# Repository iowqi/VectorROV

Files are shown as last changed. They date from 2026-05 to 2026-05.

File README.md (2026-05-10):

# VectorROV



**Languages:** [English](README.md) · [中文](README.zh-CN.md)

Open-source **tethered underwater ROV** platform built around **four vectored thrusters**, **dual fisheye panoramic perception**, and a VR-oriented teleoperation stack. This repository accompanies a **graduate design project** ([Fujian University of Technology](https://www.fjut.edu.cn/) · Computer Science) that stitches together mechanics, embedded control, edge vision/streaming, and simulation-based control experiments.

The vehicle targets highly maneuverable motion with an **8-actuator** layout (four steering motors + four thrusters) and leaves room for **dual expandable 6‑DOF manipulators** (see [TODO](#todo)).

---

## 🤖 Prototype at a glance

<p align="center">
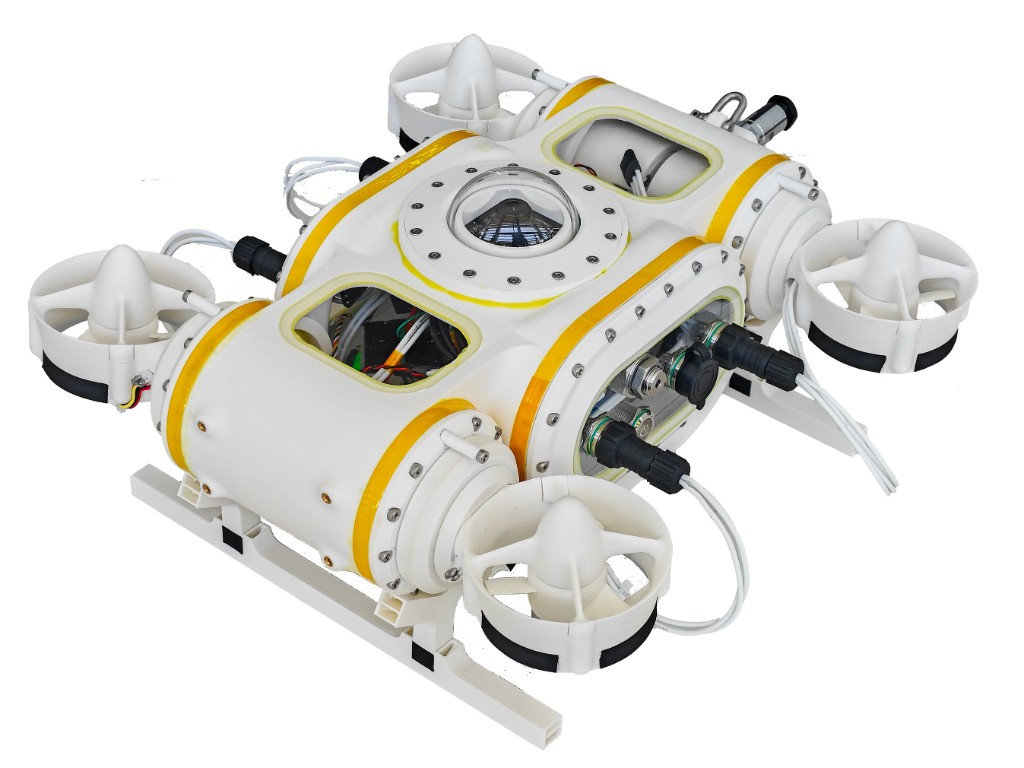
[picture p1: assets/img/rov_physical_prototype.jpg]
VectorROV physical prototype
  
</p>

<p align="center"><em>Physical prototype: four shrouded thrusters, sealed hull & domes, sled-type display stand, and bulkhead interfaces for tether/power.</em></p>

---

## ✨ Highlights

- **🧭 Four-vector propulsion** — vectored thrusters for richer force/moment authority; magnetic quick-release watertight passages for maintenance (see thesis mechanical chapter).
- **⚙️ STM32H723 + CAN** — dual **FDCAN** buses: steering (DM3510 class) vs. propulsion (**VESC / FOC**); IMU + pressure feedback for closed-loop state estimation.
- **👁️ Panorama → NDI → VR** — dual fisheye **stitch** on a **Radxa Dragon Q6A**-class edge node, **NDI** streaming, buoy Wi‑Fi hop to headset; lightweight **YOLO**-style detection with a “edge primary / client fallback” path.
- **🎮 MuJoCo + SB3** — simulation environment for control validation and **reinforcement-learning** experiments (Stable-Baselines3), aligned with the same action/state semantics as the real stack where possible.
- **🧰 CAD & tooling** — `hardware/` mechanical sources; `tools/OpenProp/` for propeller/motor analysis workflows.

### Measured/Pilot metrics (lab)

From integrated testing described in the thesis: panoramic pipeline about **~20 fps**, **capture → stitch → NDI** latency about **&lt;100 ms** (before headset render); single thruster thrust roughly **8–10 N** (estimated range).

---

## 🏗️ Architecture diagrams

| System overview (Ch.2) | Electronics & comms (Ch.2) |
|:-:|:-:|
| System overview | Electronics subsystem |

| Vision & streaming (Ch.2) | Attitude control & allocation (Ch.4) |
|:-:|:-:|
| Vision pipeline | Attitude control |

---

## 🗂️ Repository layout

| Path | Role |
|---|---|
| `assets/diagrams/` | Thesis figures (SVG): architecture, subsystems, simulation |
| `assets/img/` | Photos & renders (e.g., prototype) |
| `firmware/` | `CtrBoard-H7_CAN/` (H7 main), `F103C8T6/`, `N630/` — USB/CAN/motor control |
| `hardware/` | CAD & part sources (shells, thrusters, connectors, arms, etc.) |
| `control/MuJoCoSim/` | MuJoCo scenes, training scripts, logs/models for SB3 experiments |
| `pytest/` | Python-side checks (may ship a local `.venv`) |
| `tools/OpenProp/` | OpenProp examples & sources for prop analysis |

---

## 🚀 Getting started (pointers)

**Firmware:** Open `firmware/CtrBoard-H7_CAN/MDK-ARM` in **Keil MDK** (STM32H7). Expect long build trees—work from CubeMX-exported project files already in-repo.

**Simulation / RL:** See `control/MuJoCoSim/` — create a clean virtual environment, install MuJoCo / Gymnasium / Stable-Baselines3 stack as used by the training scripts there, then run training or evaluation entrypoints (see files under `train/`).

**Vision / NDI / edge:** Runtime primarily targets the **Q6A** edge device for stitching & inference; VR display assumes a receiver path (e.g., NDI + headset app). Treat this repo as the **system reference + firmware/hardware/sim** anchor; edge images may live on device or separate release artifacts.

---

## 🎓 Academic context

This platform is developed as a **final-year capstone / graduation design** project:

**“Design and Implementation of an Underwater ROV VR Platform with Integrated Visual Perception.”**  
It emphasizes **end-to-end integration**—mechanics, embedded control, panoramic vision, and simulation—rather than a single algorithmic benchmark. A full narrative, equations, and experiment logs appear in the student thesis manuscript (not shipped in this repo as required reading).

---

## TODO

Work that is **partially done**, **not production-ready**, or **not yet started**:

- [ ] **Reinforcement learning** — expand SB3/MuJoCo training, reward design, sim-to-real safeguards, and logging/replay for the physical ROV.
- [ ] **Dual 6‑DOF manipulators** — mechanical integration, water‑tight routing, arm control stack, and teleoperation UX (hardware CAD folders exist; full arm workflow is incomplete).
- [ ] **Meta Quest 2 VR client** — production-quality **Quest 2** client (latency-hardened rendering, interaction, connectivity with NDI/stream stack); **little or no** usable client is in-tree yet.

Contributions and issue reports are welcome.

---

## 📄 License

This project is released under the **MIT License** — see [`LICENSE`](LICENSE).

---

## 🙏 Acknowledgements

Thanks to thesis advisors and lab partners who supported machining, wet testing prep, and embedded bring-up. Third-party MCU stacks (STM32 HAL, FreeRTOS, USB stacks) remain under their respective licenses inside `firmware/`.

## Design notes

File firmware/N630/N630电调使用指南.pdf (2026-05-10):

# N630电调使用指南

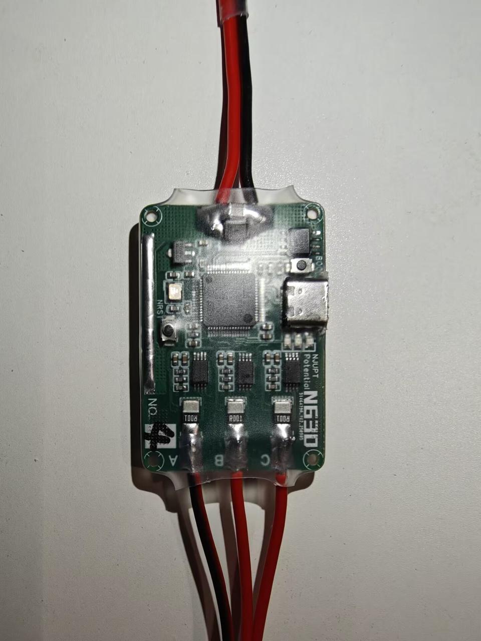
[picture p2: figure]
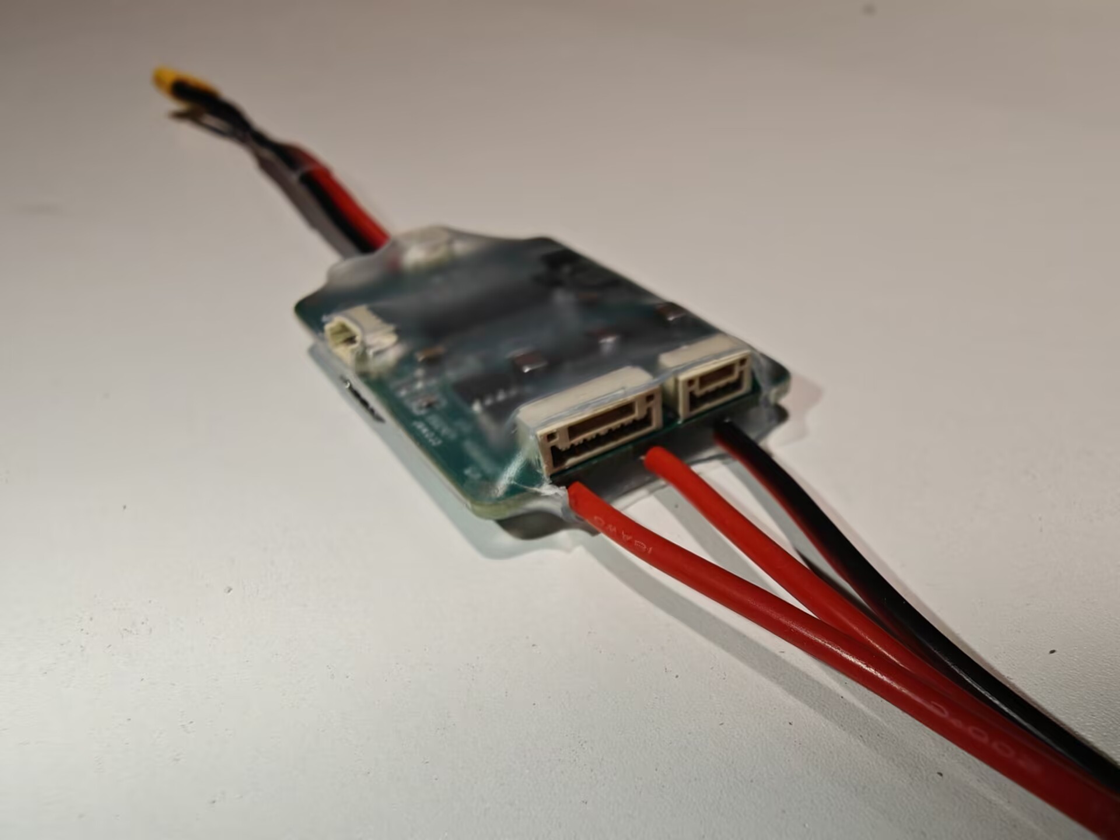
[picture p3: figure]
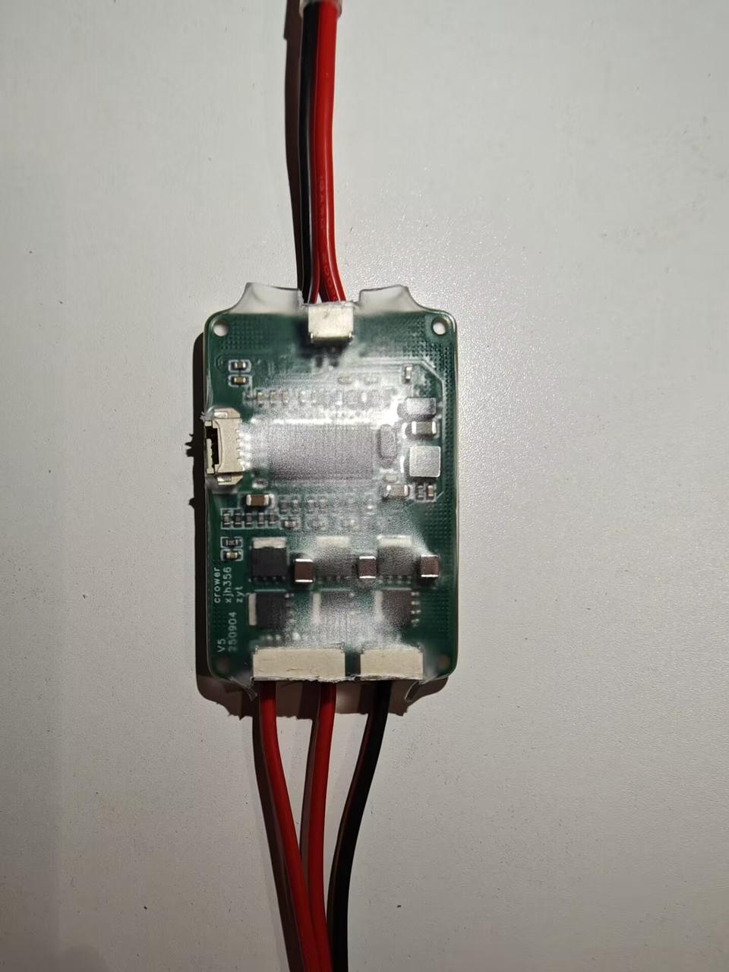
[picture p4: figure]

N630电调基于VESC项目进行设计，硬件在vesc6原版设计上进行精简，支持VESC官方上位机调参，支 持有感/无感驱动直流无刷电机，支持M3508、M2006电机编码器接入。

编译固件只需要修改采样电阻和电流放大器参数（N630电调的采样电阻为1mR，电流放大器倍数为 50）。

## 1. 线路连接

1. 将N630电调的三相线连接M3508电机，7Pin口可根据需要选择是否连接。若连接7Pin口，可使用 编码器闭环模式，可读到电机温度（过温保护功能有效）；若不连接7Pin口，仍可使用高频注入实 现零速力矩保持，但不可闭位置环。
2. 将N630电调连接电池供电。强烈建议使用电池供电，调压电源无法吸收电流，电机刹车会导致母 线电压升高，烧毁电调和母线上的其他设备！
3. 使用Type-C数据线将N630电调连接电脑。

## 2. 电机校准

1. 启动 vesc_tool_6.05.exe
2. 点击软件右上角连接按钮

2. 恢复默认设置，依次点击右侧按钮

第一个按钮是恢复默认参数，第二个按钮是写入到电机

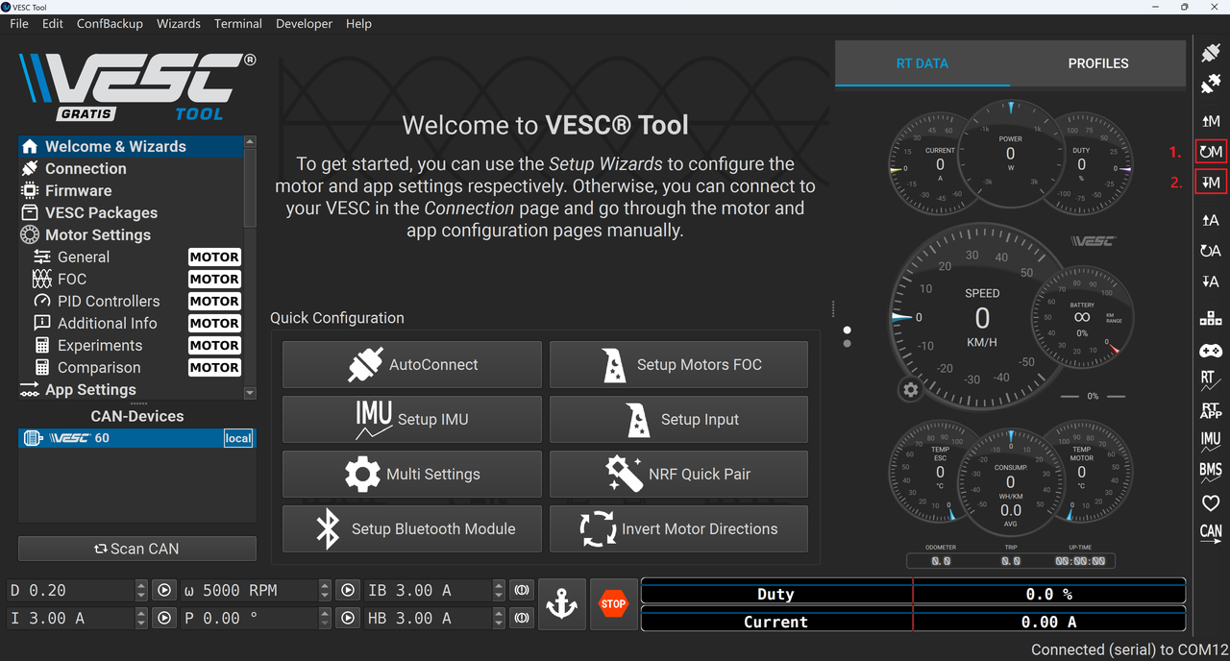
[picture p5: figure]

3. 点击左侧 General 选项卡，设置最大电流

对于M3508，设置最大电流为20A，最大刹车电流为-20A（如果使用电源调试，请设置为0A，以免烧 毁电调和母线上的其他设备）

绝对最大电流设置为60A（最大电流的三倍，超过此电流将触发报错）

4. 电机左侧 FOC 选项卡，校准电机

点击 RL 按钮后，电机会发出尖锐的声音，是在测量相电阻、相电感

点击 λ 按钮后，电机会开始转动，是在测量磁链

点击 Apply 按钮，会自动计算电流环 PI 参数

点击 ⬇M 按钮，写入参数到电机

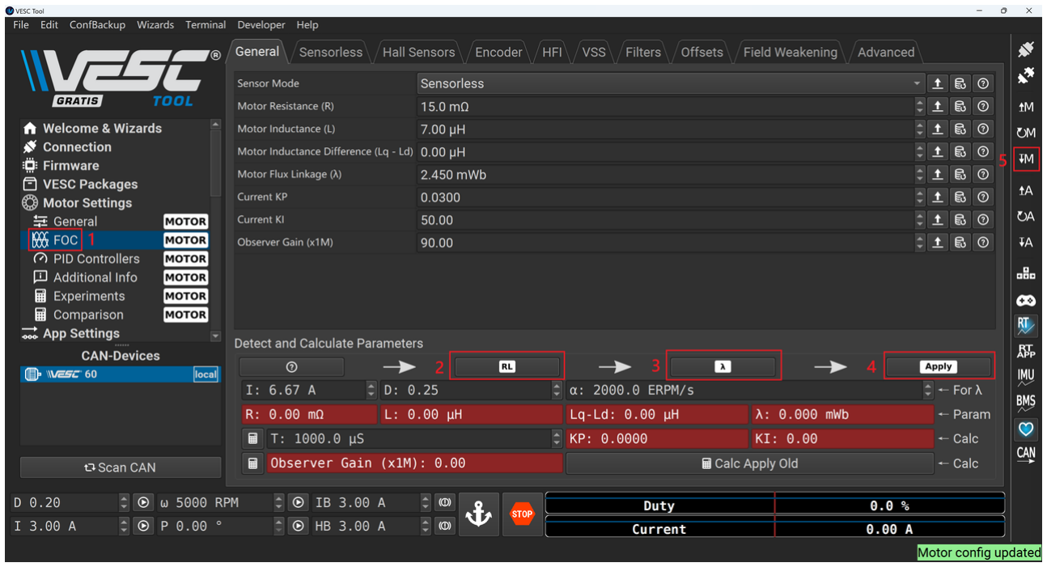
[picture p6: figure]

## 3. 首次运行

此时电机可在无感模式下运行（基于磁链观测器进行FOC控制）

点开右侧栏 RT 按钮，可实时查看电机占空比和电流，出现任何问题可点击右侧 STOP 停止，注意不能 让电机长时间通过大电流

可分别尝试占空比模式、电流模式，初次尝试请用较小的值

- 设置占空比为5%，电机开始低速转动，点击右侧 STOP 按钮停止
- 设置电流为0.5A，电机开始加速运动（直至最大速度），可随时点击右侧 STOP 按钮停止

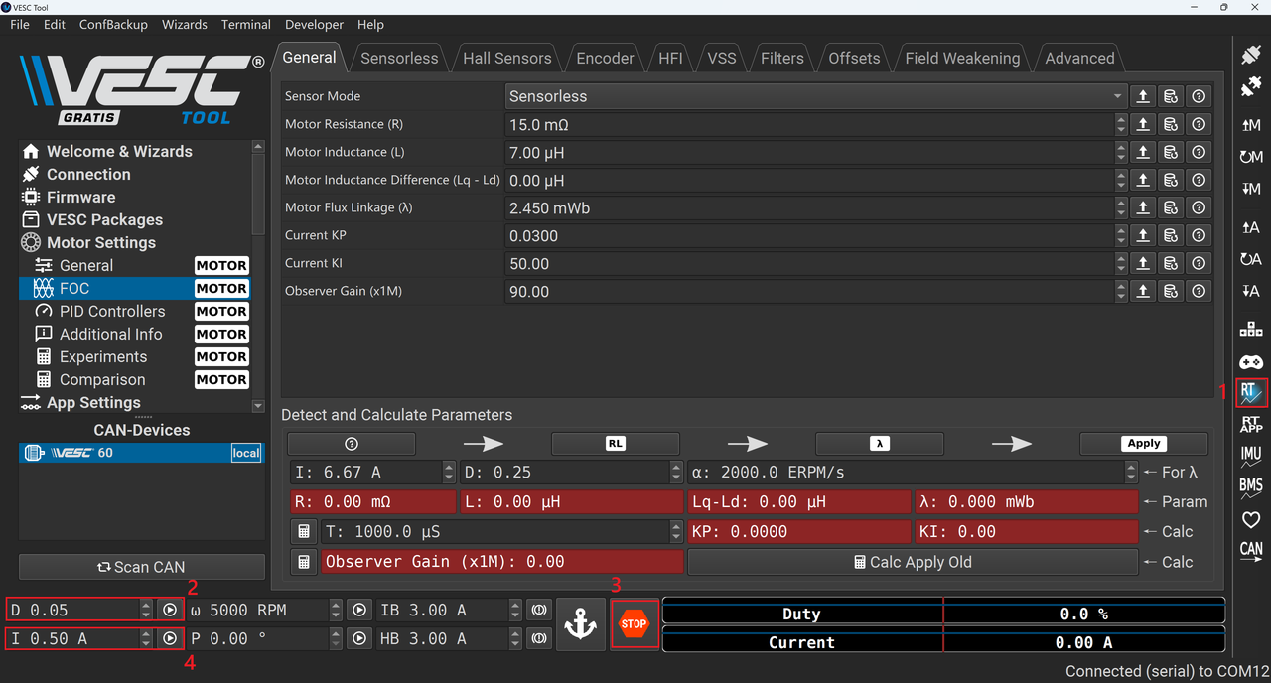
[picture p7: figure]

## 4. 使用高频注入，实现零速力矩保持

切换模式为HFI（高频注入），点击右侧 ⬇M 保存

设置 占空比5% 运行，此时电机会转动同时发出高频声音，这是正常现象

尝试用手捏住电机，能感受到电机在堵转时仍然能保持力矩输出

## 5. 使用编码器模式

M3508 7Pin 定义如下，编码器类型为 sin/cos 编码器

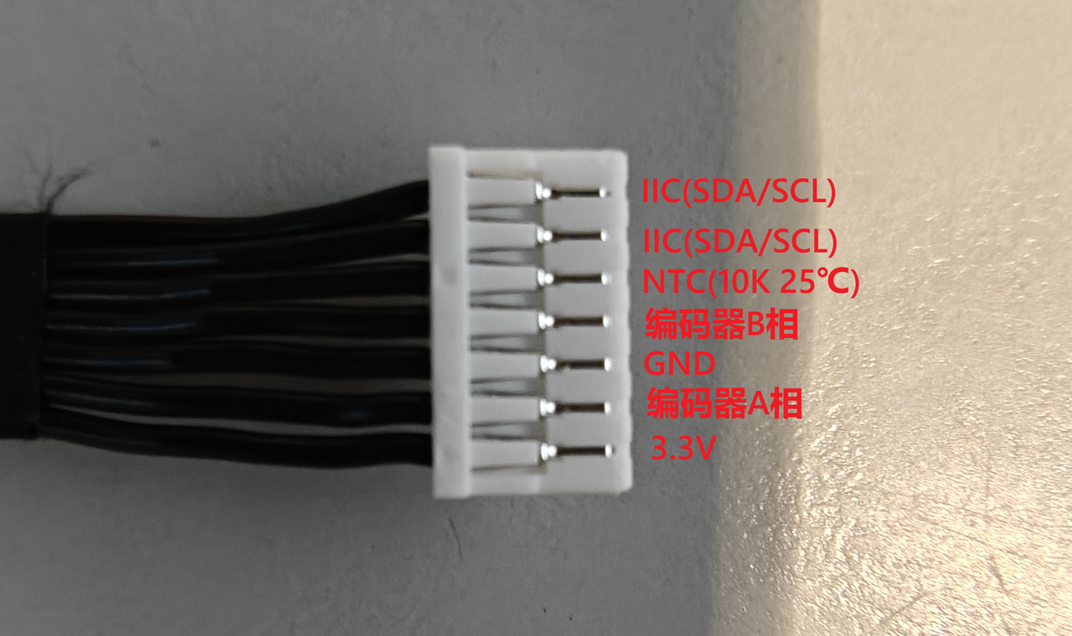
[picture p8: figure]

点击左侧 General 选项卡，修改编码器类型为 Sin/Cos Encoder，修改编码器幅值为 0.75V，偏置为 1.0V

注：此处幅值为单边幅值，编码器输出信号峰峰值为1.5V

设置完成后，点击右侧栏 ⬇M 保存配置

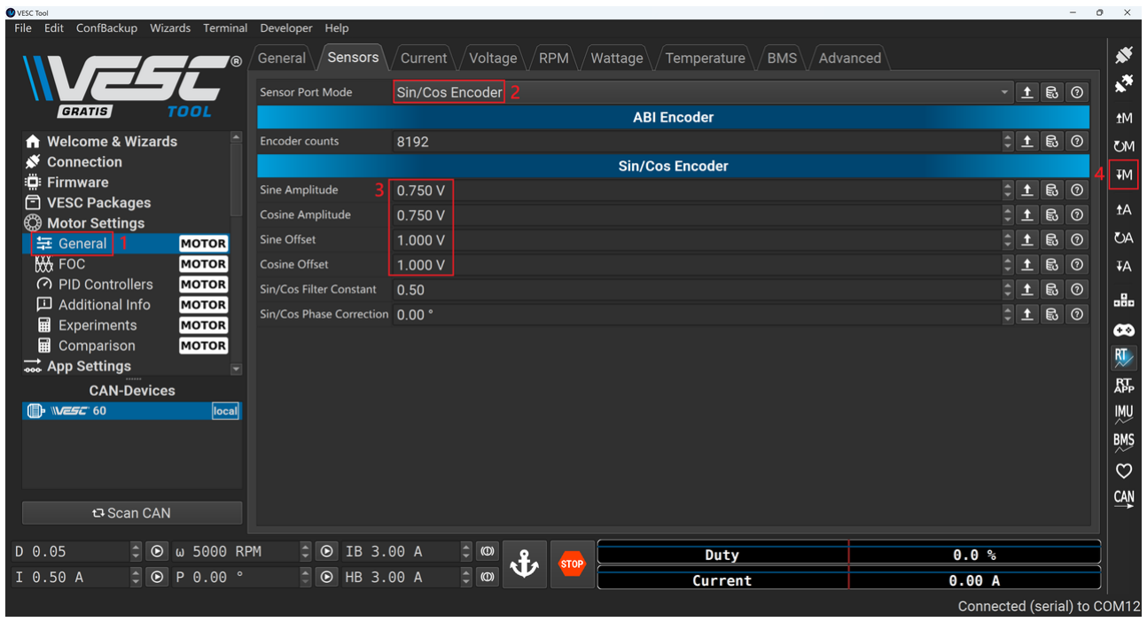
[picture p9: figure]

校准编码器

- 点击左侧 FOC 选项卡，切换到 Encoder 子选项
- 输入 5A 电流运行校准（建议使用电机最大电流的1/4，过大的电流容易烧毁电机）
- 电机开始缓慢转动，等待校准成功提示（若校准卡住超过1分钟，请检查编码器连线）
- 应用并写入配置

编码器模式设置完成后，可尝试给5%占空比，用手捏住电机，测试堵转力矩保持

## 6. 速度环与位置环

无感模式可以闭速度环，编码器模式可以闭速度环和位置环，可在左侧 PID Controllers 选项卡调节 PID参数（默认参数效果不好）

注：速度单位为电角度（ERPM），M3508的极对数为7，所以转子转一圈为7个电角度，如果有减速箱 需要另外计算。闭位置环时，请算好输出轴转一圈是多少电角度，填入 PID Controllers -> Position Angle Division

## 7. CAN通信

默认CAN通信波特率为500K，可在下图位置修改

此处为修改 App Settings，保存请使用 ⬇A 按钮

CAN通信格式详见：
https://github.com/vedderb/bldc/blob/master/documentation/comm_can.md

## 8. 更新固件

截止目前，vesc已推出 6.06 版本。若要适配新版本，需要自行修改固件参数进行编译。步骤如下

1. 克隆vesc官方代码：https://github.com/vedderb
2. 修改参数，hwconf/trampa/vesc6/hw_60_core.h 文件
a. 修改 CURRENT_AMP_GAIN 为 50.0
b. 修改 CURRENT_SHUNT_RES 为 0.001
3. 按照 README 文件配置好环境后，使用 make 60 命令编译
4. 可使用官方上位机或stm32烧录工具写入固件

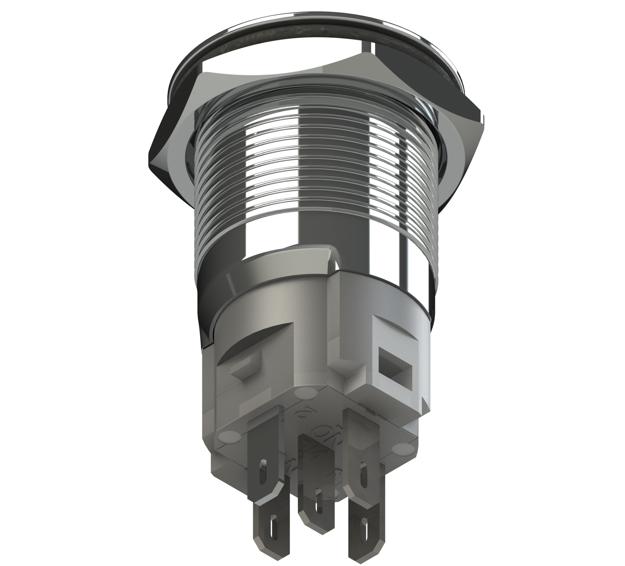
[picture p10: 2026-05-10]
hardware/LED_Button16mm/Button_16mm_2.png

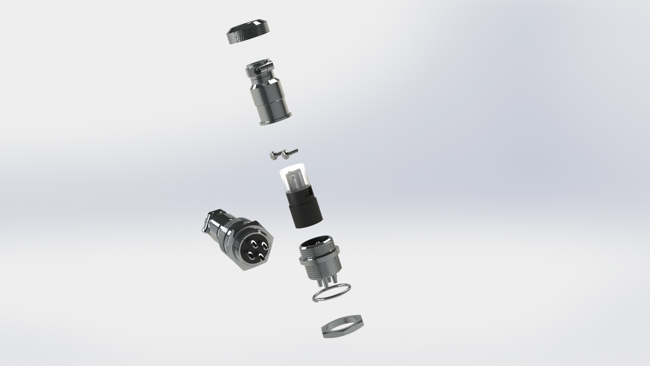
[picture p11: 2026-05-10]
hardware/gx16-connector/Connetor GX16.JPG

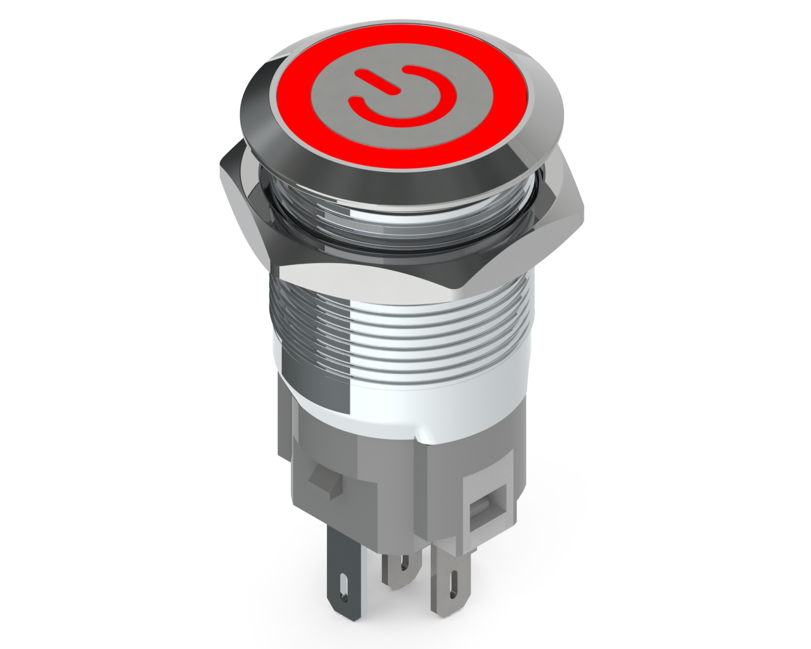
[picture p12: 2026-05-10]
hardware/LED_Button16mm/Button_16mm_1.png

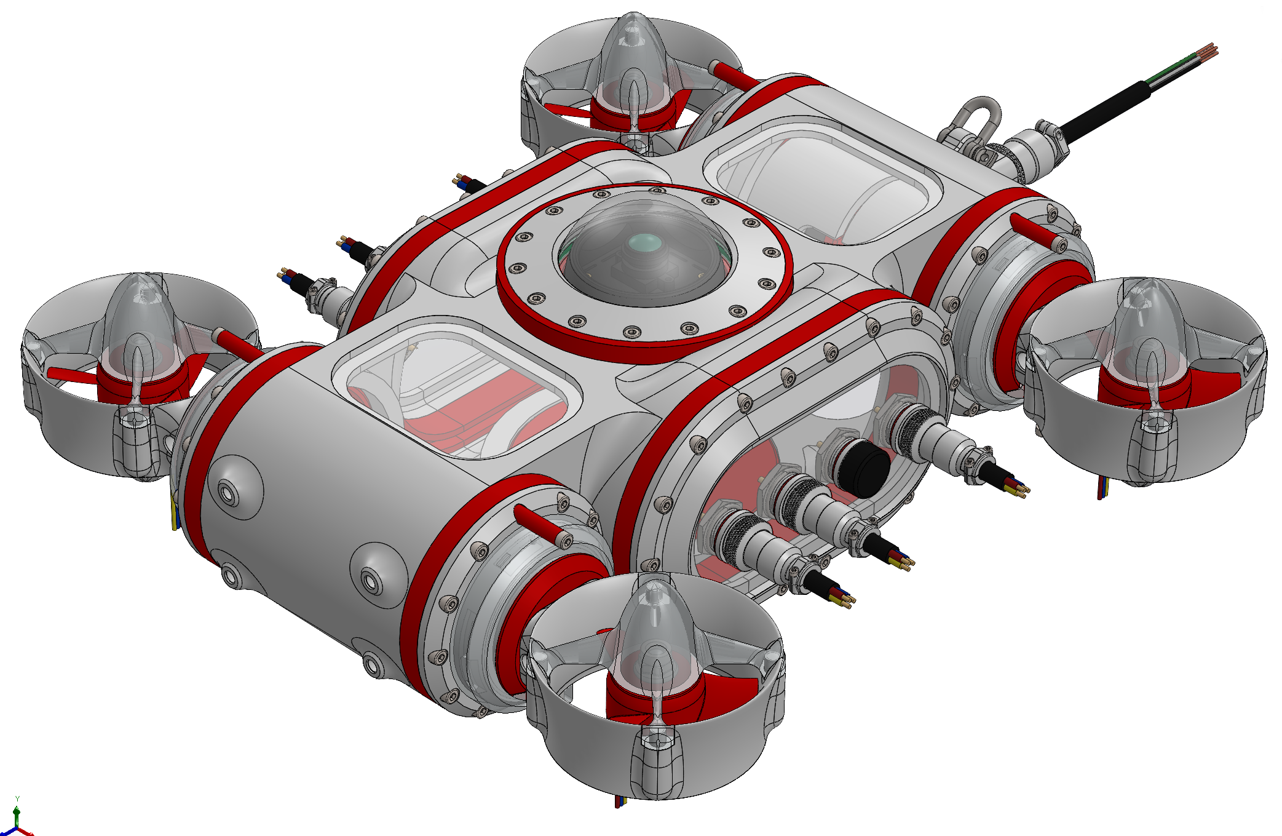
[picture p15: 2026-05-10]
assets/img/rov_prototype.png

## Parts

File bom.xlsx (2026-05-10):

分类 | 名称/链接 | 规格 | 价格 | 批量 | 单价 | 运费 | 数量 | 总价 | 类总价 | BOM总价
密封圈 | 氟胶O型圈 (https://item.taobao.com/item.htm?id=673574488705&from=cart&skuId=5711071359906&upStreamPrice=1620) | 外径112*4 | 16.2 | 2 | 8.1 | 0 | 2 | 16.2 | 26.3 | 2688.9828
 | 氟胶O型圈 (https://item.taobao.com/item.htm?id=774230751154&from=cart&skuId=5469033463785&upStreamPrice=330) | 外径60*4 | 3.3 | 2 | 1.65 | 0 | 4 | 6.6
 | 氟胶O型圈 (https://item.taobao.com/item.htm?id=774230751154&from=cart&skuId=5469033463787&upStreamPrice=350) | 外径70*4 | 3.5 | 2 | 1.75 | 0 | 2 | 3.5
电池 | 6S远航电池 (https://item.taobao.com/item.htm?id=838880984185&from=cart&skuId=5946761481635&upStreamPrice=15930) | 亿纬6S1P | 159.3 | 1 | 159.3 | 0 | 1 | 159.3 | 191.3
 | 三元锂电保护板 (https://item.taobao.com/item.htm?id=875391725096&from=cart&skuId=5880358639395&upStreamPrice=3200) | 6S 50A+NTC温感 | 32 | 1 | 32 | 0 | 1 | 32
电子 | GC2093摄像头 | - | 60 | 1 | 60 | 0 | 2 | 120 | 1239
 | IP68防水开关 (https://item.taobao.com/item.htm?id=797044978629&from=cart&skuId=5435698057369&upStreamPrice=2000) | 白色灯自复16mm | 20 | 1 | 20 | 0 | 1 | 20
 | 瑞莎Q6A (https://item.taobao.com/item.htm?id=962936728970&from=cart&skuId=6119740358776&upStreamPrice=87900) | 12G+256固态 | 1099 | 1 | 1099 | 0 | 1 | 1099
 | N630电调 (https://oshwhub.com/njupt-robomasters/n630) | - | 30 | 1 | 30 | 0 | 4 | 120
 | 2312A无刷电机 (https://item.taobao.com/item.htm?id=965539482681) | 正螺纹 | 8.8 | 1 | 8.8 | 6 | 4 | 41.2
 | DMH3510 (https://item.taobao.com/item.htm?id=871173947758&from=cart&skuId=5872003791067&upStreamPrice=22000) | 电机(含驱动) | 220 | 1 | 220 | 12 | 4 | 892
磁铁 | 圆柱形磁铁 (https://item.taobao.com/item.htm?id=918274679105&from=cart&skuId=5956275279443&upStreamPrice=1125) | 5x15mm | 11.25 | 20 | 0.5625 | 0 | 16 | 9 | 66.472
 | 圆柱形磁铁 (https://item.taobao.com/item.htm?id=918274679105&from=cart&skuId=5956275279439&upStreamPrice=550) | 5x5mm | 5.5 | 20 | 0.275 | 0 | 32 | 8.8
 | 圆柱形磁铁 (https://item.taobao.com/item.htm?id=918274679105&from=cart&skuId=5956275279463&upStreamPrice=1521) | 10x15mm | 15.21 | 10 | 1.521 | 0 | 32 | 48.672
轴承 | 尼龙POM轴承 (https://item.taobao.com/item.htm?id=782440333215&from=cart&skuId=5341835656817&upStreamPrice=370) | 6006-2RS(密封) | 3.7 | 1 | 3.7 | 0 | 4 | 14.8
 | 深沟球轴承 (https://item.taobao.com/item.htm?id=619718750156&from=cart&skuId=5738161741449&upStreamPrice=270) | 61806-2RS | 2.7 | 1 | 2.7 | 0 | 4 | 10.8
连接器 | GX16航空插头 (https://item.taobao.com/item.htm?id=715467235763&from=cart&skuId=5175080435883&upStreamPrice=20) | GX16-10芯{整套) | 5.2 | 1 | 5.2 | 0 | 7 | 36.4
紧固件 | 304法兰防松螺母 (https://item.taobao.com/item.htm?id=601483825433&from=cart&skuId=5351621079821&upStreamPrice=142) | M6 | 2.75 | 5 | 0.55 | 0 | 4 | 2.2 | 28.7108
 | 热熔螺母 (https://item.taobao.com/item.htm?id=829126153985&from=cart&skuId=5576291013934&upStreamPrice=920) | M3*6*5 | 12.8 | 80 | 0.16 | 0 | 116 | 18.56
 | 杯头内六角 (https://item.taobao.com/item.htm?id=39229349352) | M3X30 | 2.77 | 20 | 0.1385 | 0 | 4 | 0.554
 | 杯头内六角 (https://item.taobao.com/item.htm?id=829276904010&from=cart&skuId=5739116711092&upStreamPrice=706) | M3X10 | 3.79 | 100 | 0.0379 | 0 | 84 | 3.1836
 | 杯头内六角 (https://item.taobao.com/item.htm?id=829276904010&from=cart&skuId=5739116711092&upStreamPrice=706) | M3X8 | 3.79 | 100 | 0.0379 | 0 | 60 | 2.274
 | 杯头内六角 (https://item.taobao.com/item.htm?id=39229349352) | M3X5 | 2.62 | 50 | 0.0524 | 0 | 4 | 0.2096
 | 杯头内六角 (https://item.taobao.com/item.htm?id=732630255887) | M2.5X10 | 3.2 | 100 | 0.032 | 0 | 24 | 0.768
 |  | M2.5X15 | 2.13 | 100 | 0.0213 | 0 | 16 | 0.3408
 | 沉头内梅花 (https://item.taobao.com/item.htm?id=42092422468) | M3X5 | 3.88 | 100 | 0.0388 | 0 | 16 | 0.6208
 | 亚克力半球 (https://item.taobao.com/item.htm?id=779417305529) | 60mm有边无孔 | 6 | 1 | 6 | 0 | 2 | 12
 | LED聚光灯 (https://item.taobao.com/item.htm?id=654604396342) | 24V小号 | 5 | 1 | 5 | 0 | 2 | 10
 |  |  |  |  | 0 |  |  | 0
 |  |  |  |  | 0 |  |  | 0
 |  |  |  |  | 0 |  |  | 0
 |  |  |  |  | 0 |  |  | 0
 |  |  |  |  | 0 |  |  | 0
 |  |  |  |  | 0 |  |  | 0
 |  |  |  |  | 0 |  |  | 0
 |  |  |  |  | 0 |  |  | 0
 |  |  |  |  | 0 |  |  | 0
 |  |  |  |  | 0 |  |  | 0
 |  |  |  |  | 0 |  |  | 0
 |  |  |  |  | 0 |  |  | 0
 |  |  |  |  | 0 |  |  | 0
 |  |  |  |  | 0 |  |  | 0
 |  |  |  |  | 0 |  |  | 0
 |  |  |  |  | 0 |  |  | 0
 |  |  |  |  | 0 |  |  | 0
 |  |  |  |  | 0 |  |  | 0
 |  |  |  |  | 0 |  |  | 0
 |  |  |  |  | 0 |  |  | 0
 |  |  |  |  | 0 |  |  | 0
 |  |  |  |  | 0 |  |  | 0
 |  |  |  |  | 0 |  |  | 0
 |  |  |  |  | 0 |  |  | 0
 |  |  |  |  | 0 |  |  | 0
 |  |  |  |  | 0 |  |  | 0
 |  |  |  |  | 0 |  |  | 0
 |  |  |  |  | 0 |  |  | 0
 |  |  |  |  | 0 |  |  | 0
 |  |  |  |  | 0 |  |  | 0
 |  |  |  |  | 0 |  |  | 0
 |  |  |  |  | 0 |  |  | 0
 |  |  |  |  | 0 |  |  | 0
 |  |  |  |  | 0 |  |  | 0
 |  |  |  |  | 0 |  |  | 0
 |  |  |  |  | 0 |  |  | 0
 |  |  |  |  | 0 |  |  | 0
 |  |  |  |  | 0 |  |  | 0
 |  |  |  |  | 0 |  |  | 0
 |  |  |  |  | 0 |  |  | 0
 |  |  |  |  | 0 |  |  | 0
 |  |  |  |  | 0 |  |  | 0
 |  |  |  |  | 0 |  |  | 0
 |  |  |  |  | 0 |  |  | 0
 |  |  |  |  | 0 |  |  | 0
 |  |  |  |  | 0 |  |  | 0
 |  |  |  |  | 0 |  |  | 0
 |  |  |  |  | 0 |  |  | 0
 |  |  |  |  | 0 |  |  | 0
 |  |  |  |  | 0 |  |  | 0
 |  |  |  |  | 0 |  |  | 0
 |  |  |  |  | 0 |  |  | 0
 |  |  |  |  | 0 |  |  | 0
 |  |  |  |  | 0 |  |  | 0
 |  |  |  |  | 0 |  |  | 0
 |  |  |  |  | 0 |  |  | 0
 |  |  |  |  | 0 |  |  | 0
 |  |  |  |  | 0 |  |  | 0
 |  |  |  |  | 0 |  |  | 0
 |  |  |  |  | 0 |  |  | 0
 |  |  |  |  | 0 |  |  | 0
 |  |  |  |  | 0 |  |  | 0
 |  |  |  |  | 0 |  |  | 0
 |  |  |  |  | 0 |  |  | 0
 |  |  |  |  | 0 |  |  | 0
 |  |  |  |  | 0 |  |  | 0
 |  |  |  |  | 0 |  |  | 0
 |  |  |  |  | 0 |  |  | 0
 |  |  |  |  | 0 |  |  | 0
 |  |  |  |  | 0 |  |  | 0
 |  |  |  |  | 0 |  |  | 0
 |  |  |  |  | 0 |  |  | 0
 |  |  |  |  | 0 |  |  | 0
 |  |  |  |  | 0 |  |  | 0
 |  |  |  |  | 0 |  |  | 0
 |  |  |  |  | 0 |  |  | 0
 |  |  |  |  | 0 |  |  | 0
 |  |  |  |  | 0 |  |  | 0
 |  |  |  |  | 0 |  |  | 0
 |  |  |  |  | 0 |  |  | 0
 |  |  |  |  | 0 |  |  | 0
 |  |  |  |  | 0 |  |  | 0
 |  |  |  |  | 0 |  |  | 0
 |  |  |  |  | 0 |  |  | 0
 |  |  |  |  | 0 |  |  | 0
 |  |  |  |  | 0 |  |  | 0
 |  |  |  |  | 0 |  |  | 0
 |  |  |  |  | 0 |  |  | 0
 |  |  |  |  | 0 |  |  | 0
 |  |  |  |  | 0 |  |  | 0
 |  |  |  |  | 0 |  |  | 0
 |  |  |  |  | 0 |  |  | 0
 |  |  |  |  | 0 |  |  | 0
 |  |  |  |  | 0 |  |  | 0
 |  |  |  |  | 0 |  |  | 0
 |  |  |  |  | 0 |  |  | 0
 |  |  |  |  | 0 |  |  | 0
 |  |  |  |  | 0 |  |  | 0
 |  |  |  |  | 0 |  |  | 0
 |  |  |  |  | 0 |  |  | 0
 |  |  |  |  | 0 |  |  | 0
 |  |  |  |  | 0 |  |  | 0
 |  |  |  |  | 0 |  |  | 0
 |  |  |  |  | 0 |  |  | 0
 |  |  |  |  | 0 |  |  | 0
 |  |  |  |  | 0 |  |  | 0
 |  |  |  |  | 0 |  |  | 0
 |  |  |  |  | 0 |  |  | 0
 |  |  |  |  | 0 |  |  | 0
 |  |  |  |  | 0 |  |  | 0
 |  |  |  |  | 0 |  |  | 0
 |  |  |  |  | 0 |  |  | 0
 |  |  |  |  | 0 |  |  | 0
 |  |  |  |  | 0 |  |  | 0
 |  |  |  |  | 0 |  |  | 0
 |  |  |  |  | 0 |  |  | 0
 |  |  |  |  | 0 |  |  | 0
 |  |  |  |  | 0 |  |  | 0
 |  |  |  |  | 0 |  |  | 0
 |  |  |  |  | 0 |  |  | 0
 |  |  |  |  | 0 |  |  | 0
 |  |  |  |  | 0 |  |  | 0
 |  |  |  |  | 0 |  |  | 0
 |  |  |  |  | 0 |  |  | 0
 |  |  |  |  | 0 |  |  | 0
 |  |  |  |  | 0 |  |  | 0
 |  |  |  |  | 0 |  |  | 0
 |  |  |  |  | 0 |  |  | 0
 |  |  |  |  | 0 |  |  | 0
 |  |  |  |  | 0 |  |  | 0
 |  |  |  |  | 0 |  |  | 0
 |  |  |  |  | 0 |  |  | 0
 |  |  |  |  | 0 |  |  | 0
 |  |  |  |  | 0 |  |  | 0
 |  |  |  |  | 0 |  |  | 0
 |  |  |  |  | 0 |  |  | 0
 |  |  |  |  | 0 |  |  | 0
 |  |  |  |  | 0 |  |  | 0
 |  |  |  |  | 0 |  |  | 0
 |  |  |  |  | 0 |  |  | 0
 |  |  |  |  | 0 |  |  | 0
 |  |  |  |  | 0 |  |  | 0
 |  |  |  |  | 0 |  |  | 0
 |  |  |  |  | 0 |  |  | 0
 |  |  |  |  | 0 |  |  | 0
 |  |  |  |  | 0 |  |  | 0
 |  |  |  |  | 0 |  |  | 0
 |  |  |  |  | 0 |  |  | 0
 |  |  |  |  | 0 |  |  | 0
 |  |  |  |  | 0 |  |  | 0
 |  |  |  |  | 0 |  |  | 0
 |  |  |  |  | 0 |  |  | 0
 |  |  |  |  | 0 |  |  | 0
 |  |  |  |  | 0 |  |  | 0
 |  |  |  |  | 0 |  |  | 0
 |  |  |  |  | 0 |  |  | 0
 |  |  |  |  | 0 |  |  | 0
 |  |  |  |  | 0 |  |  | 0
 |  |  |  |  | 0 |  |  | 0
 |  |  |  |  | 0 |  |  | 0
 |  |  |  |  | 0 |  |  | 0
 |  |  |  |  | 0 |  |  | 0
 |  |  |  |  | 0 |  |  | 0
 |  |  |  |  | 0 |  |  | 0
 |  |  |  |  | 0 |  |  | 0
 |  |  |  |  | 0 |  |  | 0
 |  |  |  |  | 0 |  |  | 0
 |  |  |  |  | 0 |  |  | 0
 |  |  |  |  | 0 |  |  | 0
 |  |  |  |  | 0 |  |  | 0
 |  |  |  |  | 0 |  |  | 0
 |  |  |  |  | 0 |  |  | 0
 |  |  |  |  | 0 |  |  | 0
 |  |  |  |  | 0 |  |  | 0
 |  |  |  |  | 0 |  |  | 0
 |  |  |  |  | 0 |  |  | 0
 |  |  |  |  | 0 |  |  | 0
 |  |  |  |  | 0 |  |  | 0
 |  |  |  |  | 0 |  |  | 0
 |  |  |  |  | 0 |  |  | 0
 |  |  |  |  | 0 |  |  | 0
 |  |  |  |  | 0 |  |  | 0
 |  |  |  |  | 0 |  |  | 0
 |  |  |  |  | 0 |  |  | 0
 |  |  |  |  | 0 |  |  | 0
 |  |  |  |  | 0 |  |  | 0
 |  |  |  |  | 0 |  |  | 0
 |  |  |  |  | 0 |  |  | 0
 |  |  |  |  | 0 |  |  | 0
 |  |  |  |  | 0 |  |  | 0
 |  |  |  |  | 0 |  |  | 0
 |  |  |  |  | 0 |  |  | 0
 |  |  |  |  | 0 |  |  | 0
 |  |  |  |  | 0 |  |  | 0
 |  |  |  |  | 0 |  |  | 0
 |  |  |  |  | 0 |  |  | 0
 |  |  |  |  | 0 |  |  | 0
 |  |  |  |  | 0 |  |  | 0
 |  |  |  |  | 0 |  |  | 0
 |  |  |  |  | 0 |  |  | 0
 |  |  |  |  | 0 |  |  | 0
 |  |  |  |  | 0 |  |  | 0
 |  |  |  |  | 0 |  |  | 0
 |  |  |  |  | 0 |  |  | 0
 |  |  |  |  | 0 |  |  | 0
 |  |  |  |  | 0 |  |  | 0
 |  |  |  |  | 0 |  |  | 0
 |  |  |  |  | 0 |  |  | 0
 |  |  |  |  | 0 |  |  | 0
 |  |  |  |  | 0 |  |  | 0
 |  |  |  |  | 0 |  |  | 0
 |  |  |  |  | 0 |  |  | 0
 |  |  |  |  | 0 |  |  | 0
 |  |  |  |  | 0 |  |  | 0
 |  |  |  |  | 0 |  |  | 0
 |  |  |  |  | 0 |  |  | 0
 |  |  |  |  | 0 |  |  | 0
 |  |  |  |  | 0 |  |  | 0
 |  |  |  |  | 0 |  |  | 0
 |  |  |  |  | 0 |  |  | 0
 |  |  |  |  | 0 |  |  | 0
 |  |  |  |  | 0 |  |  | 0
 |  |  |  |  | 0 |  |  | 0
 |  |  |  |  | 0 |  |  | 0
 |  |  |  |  | 0 |  |  | 0
 |  |  |  |  | 0 |  |  | 0
 |  |  |  |  | 0 |  |  | 0
 |  |  |  |  | 0 |  |  | 0
 |  |  |  |  | 0 |  |  | 0
 |  |  |  |  | 0 |  |  | 0
 |  |  |  |  | 0 |  |  | 0
 |  |  |  |  | 0 |  |  | 0
 |  |  |  |  | 0 |  |  | 0
 |  |  |  |  | 0 |  |  | 0
 |  |  |  |  | 0 |  |  | 0
 |  |  |  |  | 0 |  |  | 0
 |  |  |  |  | 0 |  |  | 0
 |  |  |  |  | 0 |  |  | 0
 |  |  |  |  | 0 |  |  | 0
 |  |  |  |  | 0 |  |  | 0
 |  |  |  |  | 0 |  |  | 0
 |  |  |  |  | 0 |  |  | 0
 |  |  |  |  | 0 |  |  | 0
 |  |  |  |  | 0 |  |  | 0

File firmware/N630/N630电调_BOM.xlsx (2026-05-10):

No. | Quantity | Comment | Designator | Footprint | Value | Manufacturer Part | Manufacturer | Supplier Part | Supplier
1 | 2 | 15pF | C2,C8 | C0603 | 15pF | CL10C150JB8NNNC | SAMSUNG(三星) | C1644 | LCSC
2 | 19 | 2.2uF | C3,C4,C5,C6,C9,C10,C11,C12,C14,C15,C17,C20,C31,C33,C34,C35,C36,C38,C42 | C0603 | 2.2uF | CL10A225KO8NNNC | SAMSUNG(三星) | C23630 | LCSC
3 | 3 | 100nF | C7,C28,C58 | C0603 | 100nF | CC0603KRX7R9BB104 | YAGEO(国巨) | C14663 | LCSC
4 | 2 | 10uF | C13,C64 | C0603 | 10uF | CL10A106KP8NNNC | SAMSUNG(三星) | C19702 | LCSC
5 | 1 | 6.8nF | C16 | C0603 | 6.8nF | 0603B682K500NT | FH(风华) | C1631 | LCSC
6 | 1 | 120pF | C18 | C0603 | 120pF | CC0603JRNPO9BN121 | YAGEO(国巨) | C107035 | LCSC
7 | 1 | 22nF | C19 | C0603 | 22nF | CL10B223KB8NNNC | SAMSUNG(三星) | C21122 | LCSC
8 | 1 | 15nF | C22 | C0603 | 15nF | CC0603KRX7R9BB153 | YAGEO(国巨) | C107076 | LCSC
9 | 3 | 220nF | C23,C24,C25 | C0603 | 220nF | CL10B224KA8NNNC | SAMSUNG(三星) | C21120 | LCSC
10 | 2 | 4.7uF | C26,C27 | C1206 | 4.7uF | 1206B475K500NT | FH(风华) | C29823 | LCSC
11 | 3 | 4.7nF | C29,C30,C45 | C0603 | 4.7nF | 0603B472K500NT | FH(风华) | C53987 | LCSC
12 | 1 | 100uF | C32 | C1206 | 100uF | CL31A107MQHNNNE | SAMSUNG(三星) | C15008 | LCSC
13 | 4 | 10uF | C37,C40,C43,C65 | C1210 | 10uF | CL32B106KBJNNNE | SAMSUNG(三星) | C138687 | LCSC
14 | 1 | NCD0805R1 | D1 | LED0805-R-RD |  | NCD0805R1 | 国星光电 | C84256 | LCSC
15 | 1 | KT-0805Y | D2 | LED0805-R-RD |  | KT-0805Y | KENTO | C2296 | LCSC
16 | 1 | KT-0805G | D3 | LED0805-R-RD |  | KT-0805G | KENTO | C2297 | LCSC
17 | 1 | SS56 | D4 | SMA_L4.3-W2.6-LS5.0-RD |  | SS56 | 宏迦橙 | C18199169 | LCSC
18 | 1 | SMAJ5.0A | D5 | SMA_L4.3-W2.6-LS5.2-RD |  | SMAJ5.0A | Littelfuse(美国力特) | C83329 | LCSC
19 | 1 | SMBJ26A | D6 | SMB_L4.4-W3.6-LS5.3-L-RD |  | SMBJ26A | Littelfuse(美国力特) | C315992 | LCSC
20 | 1 | 22uH | L2 | IND-SMD_L4.6-W4.2_SMMS0420 | 22uH | SMMS0420-220M | SXN(顺翔诺) | C2894720 | LCSC
21 | 1 | WAFER-GH1.25-2PWB | P2 | CONN-TH_2P-P1.25_XUNPU_WAFER-GH1.25-2PWB |  | WAFER-GH1.25-2PWB | XUNPU(讯普) | C3029377 | LCSC
22 | 1 | 532610471 | P7 | CONN-SMD_4P-P1.25_53261-0471 |  | 532610471 | MOLEX | C240847 | LCSC
23 | 1 | WAFER-GH1.25-7PWB | P13 | CONN-SMD_7P-P1.25_FWF12514-S07B24W5M |  | WAFER-GH1.25-7PWB | XUNPU(讯普) | C3029382 | LCSC
24 | 1 | WAFER-GH1.25-4PWB | P14 | CONN-SMD_4P-P1.25_XUNPU_WAFER-GH1.25-4PWB |  | WAFER-GH1.25-4PWB | XUNPU(讯普) | C3029379 | LCSC
25 | 6 | PSMN1R8-40YLC,115 | Q1,Q2,Q3,Q4,Q5,Q6 | SOT-669_L4.9-W4.0-P1.27-LS6.0-BL |  | PSMN1R8-40YLC,115 | Nexperia(安世) | C88071 | LCSC
26 | 1 | NC | R1 | R0402 | NC | MCS04020Z0000ZE000 | VISHAY(威世) |  | LCSC
27 | 5 | 10kΩ | R2,R3,R13,R28,R39 | R0603 | 10kΩ | 0603WAF1002T5E | UNI-ROYAL(厚声) | C25804 | LCSC
28 | 1 | 1kΩ | R7 | R0603 | 1kΩ | 0603WAF1001T5E | UNI-ROYAL(厚声) | C21190 | LCSC
29 | 2 | 220Ω | R8,R9 | R0603 | 220Ω | 0603WAF2200T5E | UNI-ROYAL(厚声) | C22962 | LCSC
30 | 1 | 3.3kΩ | R10 | R0603 | 3.3kΩ | 0603WAF3301T5E | UNI-ROYAL(厚声) | C22978 | LCSC
31 | 1 | 18kΩ | R11 | R0603 | 18kΩ | 0603WAF1802T5E | UNI-ROYAL(厚声) | C25810 | LCSC
32 | 1 | 15kΩ | R12 | R0603 | 15kΩ | 0603WAF1502T5E | UNI-ROYAL(厚声) | C22809 | LCSC
33 | 1 | 220kΩ | R14 | R0603 | 220kΩ | 0603WAF2203T5E | UNI-ROYAL(厚声) | C22961 | LCSC
34 | 4 | 39kΩ | R15,R17,R19,R21 | R0603 | 39kΩ | 0603WAF3902T5E | UNI-ROYAL(厚声) | C23153 | LCSC
35 | 4 | 2.2kΩ | R16,R18,R20,R22 | R0603 | 2.2kΩ | 0603WAF2201T5E | UNI-ROYAL(厚声) | C4190 | LCSC
36 | 1 | NC(120R) | R23 | R0805 | NC(120R) | 0805W8F1200T5E | UNI-ROYAL(厚声) |  | LCSC
37 | 3 | 1mΩ | R24,R29,R32 | RES-SMD_L6.3-W3.2_R2512 | 1mΩ | RE2512F3R001 | 捷而瑞 | C46961745 | LCSC
38 | 6 | 4.7Ω | R25,R26,R30,R31,R33,R34 | R0603 | 4.7Ω | 0603WAF470KT5E | UNI-ROYAL(厚声) | C23164 | LCSC
39 | 1 | KNTC0603/10KF3950 | R27 | R0603 |  | KNTC0603/10KF3950 | KUU | C2892547 | LCSC
40 | 3 | 100Ω | R35,R36,R37 | R0603 | 100Ω | 0603WAF1000T5E | UNI-ROYAL(厚声) | C22775 | LCSC
41 | 4 | M2螺丝 | TP1,TP2,TP3,TP4 | M2螺丝
42 | 1 | STM32F405RGT6 | U1 | LQFP-64_L10.0-W10.0-P0.50-LS12.0-BL |  | STM32F405RGT6 | ST(意法半导体) | C15742 | LCSC
43 | 1 | ME6118A33PG | U2 | SOT-89-3_L4.5-W2.5-P1.50-LS4.2-BR |  | ME6118A33PG | MICRONE(南京微盟) | C236721 | LCSC
44 | 1 | TJA1051T/3/1J | U4 | SOIC-8_L4.9-W3.9-P1.27-LS6.0-BL |  | TJA1051T/3/1J | NXP(恩智浦) | C38695 | LCSC
45 | 3 | INA240A2PWR | U5,U6,U7 | TSSOP-8_L4.4-W3.0-P0.65-LS6.4-BL |  | INA240A2PWR | TI(德州仪器) | C129949 | LCSC
46 | 2 | GT-TC029A-H030-L1N | U8,U10 | SW-SMD_L3.9-W2.9-P4.15-LS5.0 |  | GT-TC029A-H030-L1N | G-Switch(品赞) | C19188073 | LCSC
47 | 1 | DRV8301DCA | U9 | HTSSOP-56_L14.0-W6.0-P0.50-LS8.1-BL-EP |  | DRV8301DCA | TI(德州仪器) | C92113 | LCSC
48 | 1 | TYPE-C 16PIN 2MD(073) | USB1 | USB-C-SMD_TYPE-C-6PIN-2MD-073 |  | TYPE-C 16PIN 2MD(073) | SHOU HAN(首韩) | C2765186 | LCSC
49 | 1 | 8MHz | X1 | CRYSTAL-SMD_4P-L3.2-W2.5-BL | 8MHz | X32258MSB4SI | YXC(扬兴晶振) | C2682774 | LCSC

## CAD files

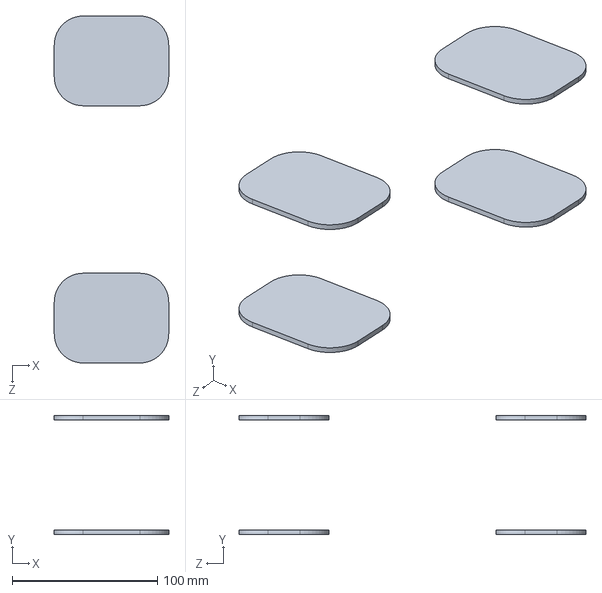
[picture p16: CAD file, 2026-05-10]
hardware/BodyShell/Cabin.SLDASM
78.8 x 82.0 x 238.8 mm
BodyShellAcrylic x 4

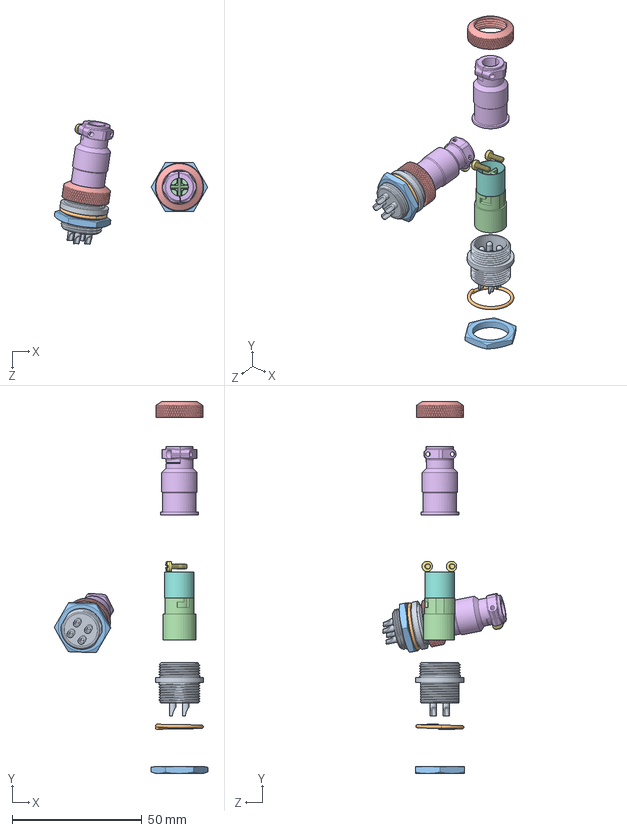
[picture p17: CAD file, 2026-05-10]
hardware/gx16-connector/Ensamblaje Conector CNC 2.SLDASM
59.2 x 143.4 x 47.6 mm
Conector CNC x 2
Conector CNC - Anillo x 2
Conector CNC - Tuerca x 2
Conector CNC - Hembra x 2
Conector CNC - Anillo Roscado x 2
Conector CNC - Capuchon x 2
pan slot head_am x 4
Conector CNC - Anillo Aislante x 2

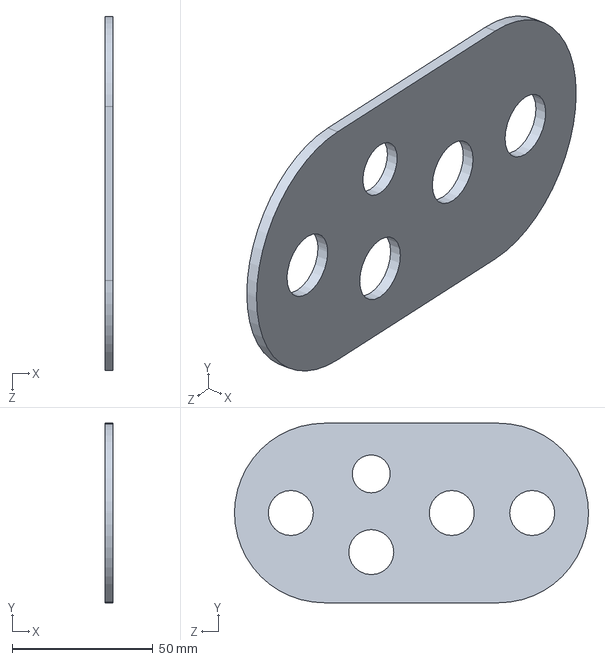
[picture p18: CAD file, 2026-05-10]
hardware/BodyCover/BodyCoverAcrylicPlus.SLDPRT
3.00 x 63.8 x 125.8 mm

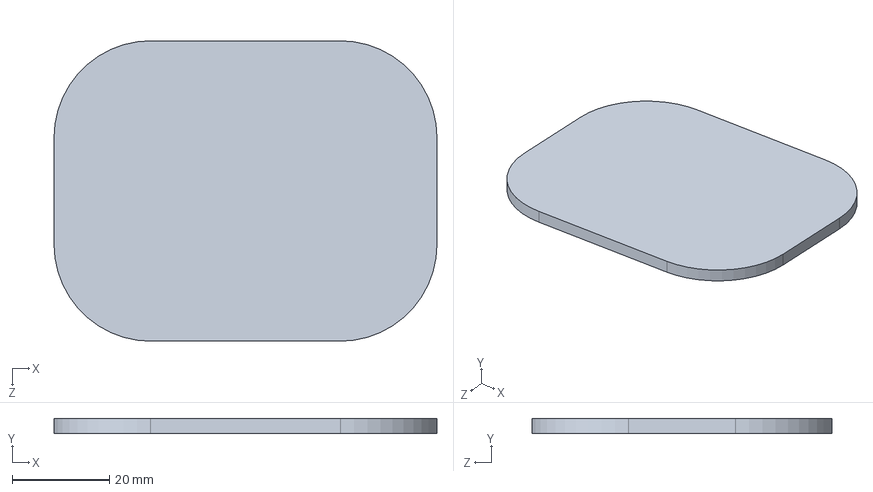
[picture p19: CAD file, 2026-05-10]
hardware/BodyShell/BodyShellAcrylic.SLDPRT
78.8 x 3.00 x 61.8 mm

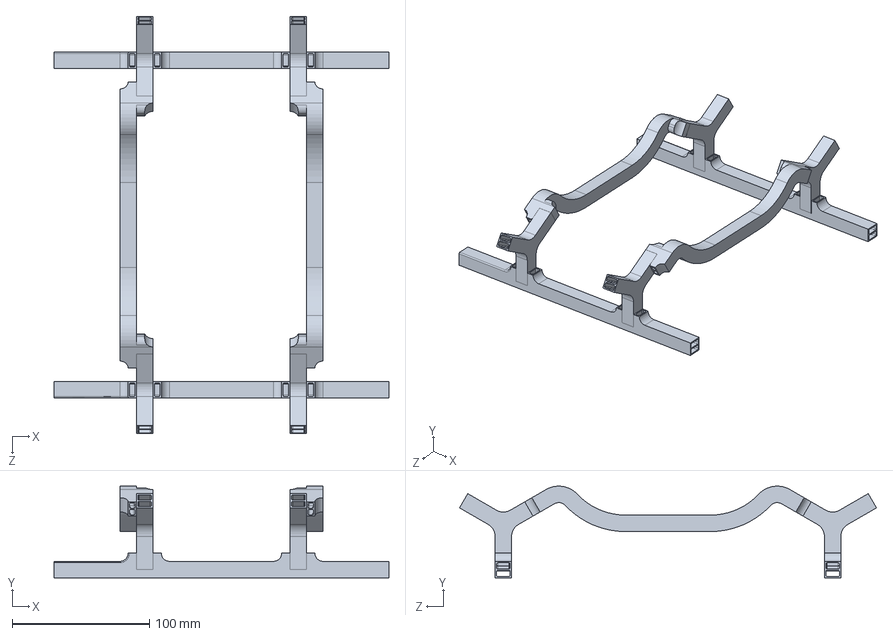
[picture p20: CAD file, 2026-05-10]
hardware/Bracket.SLDPRT
244.0 x 66.8 x 304.0 mm

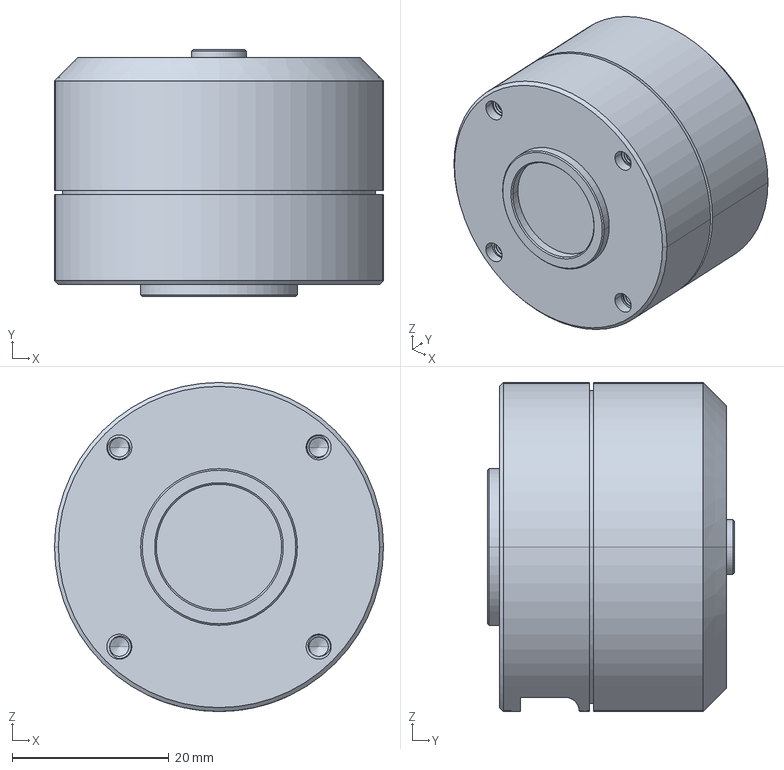
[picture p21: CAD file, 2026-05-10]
hardware/DM-H3510/DM3510-20250206_1.stp
42.0 x 31.5 x 42.0 mm

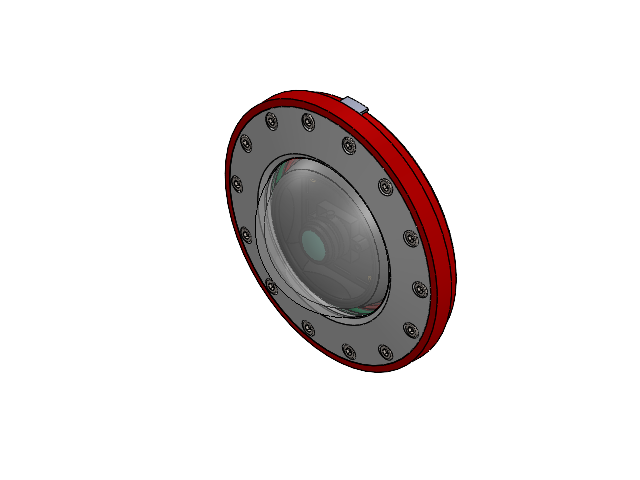
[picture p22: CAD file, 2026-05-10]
hardware/Camera/CamModule.SLDASM
DomeCover
USBCamera
CameraShell
hexagon socket head cap screws gb x 14
OringD70d4^CamModule

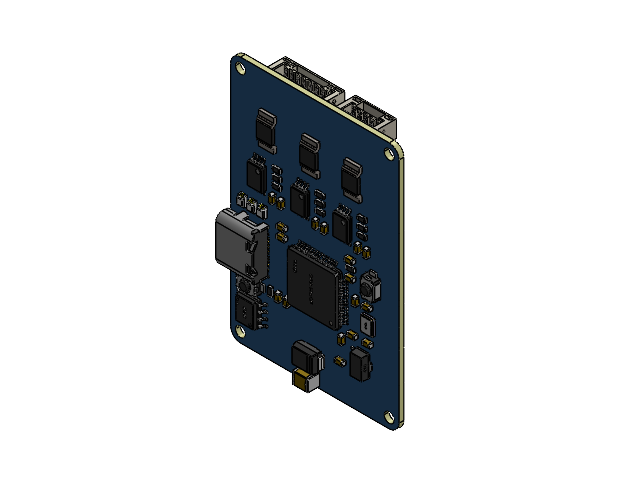
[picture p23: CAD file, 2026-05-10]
hardware/N630/N630PCB.SLDASM
C1206~C1206_L3.2-W1.6-H1.3~CGzI.step x 3
R0603~R0603~CGzI.step x 30
LED0805-R-RD~LED0805-RD~CGzI.step x 3
C0603~C0603_L1.6-W0.8-H0.8~CGzI.step x 36
TSSOP-8_L4.4-W3.0-P0.65-LS6.4-BL~TSSOP-8_L3.0-W4.4-H1.0-LS6.4-P0.65~CGzI.step x 3
CONN-TH_2P-P1.25_XUNPU_WAFER-GH1.25-2PWB~CONN-TH_2P-P1.25_XUNPU_WAFER-GH1.25-2PWB~CGzI.step
CONN-SMD_4P-P1.25_XUNPU_WAFER-GH1.25-4PWB~CONN-SMD_4P-P1.25_XUNPU_WAFER-GH1.25-4PWB~CGzI.step
RES-SMD_L6.3-W3.2_R2512~RES-SMD_L6.3-W3.2_R2512~CGzI.step x 3
SMA_L4.3-W2.6-LS5.0-RD~SMA_L4.3-W2.6-LS5.0-RD~CGzI.step
IND-SMD_L4.6-W4.2_SMMS0420~IND-SMD_L4.6-W4.2_SMMS0420~CGzI.step
CRYSTAL-SMD_4P-L3.2-W2.5-BL~CRYSTAL-SMD_4P-L3.2-W2.5-BL~CGzI.step
SOT-89-3_L4.5-W2.5-P1.50-LS4.2-BR~SOT-89-3_L4.3-W2.5-H1.6-LS4.1-P1.50~CGzI.step
SMB_L4.4-W3.6-LS5.3-L-RD~SMB_L4.4-W3.6-LS5.3-L-RD~CGzI.step
CONN-SMD_4P-P1.25_53261-0471~CONN-SMD_MX1.25-WS-4P~CGzI.step
USB-C-SMD_TYPE-C-6PIN-2MD-073~USB-C-SMD_TYPE-C-6PIN-2MD-073~CGzI.step
C1210~C1210_L3.2-W2.5-H2.5~CGzI.step x 4
CONN-SMD_7P-P1.25_FWF12514-S07B24W5M~CONN-SMD_7P-P1.25_FWF12514-S07B24W5M~CGzI.step
SW-SMD_L3.9-W2.9-P4.15-LS5.0~SW-SMD_L3.9-W2.9-H2-P4.15-LS5.0~CGzI.step x 2
SOT-669_L4.9-W4.0-P1.27-LS6.0-BL~SOT-669-4_L4.9-W3.9-H1.2-LS6.0-P1.27~CGzI.step x 6
HTSSOP-56_L14.0-W6.0-P0.50-LS8.1-BL-EP~HTSSOP-56_L14.0-W6.0-P0.50-LS8.1-BL-EP~CGzI.step
SOIC-8_L4.9-W3.9-P1.27-LS6.0-BL~SOIC-8_L4.9-W3.9-H1.7-LS6.0-P1.27~CGzI.step
R0402~R0402_L1.0-W0.5-H0.4~CGzI.step
R0805~R0805_L2.0-W1.3-H0.6~CGzI.step
SMA_L4.3-W2.6-LS5.2-RD~SMA_L4.3-W2.6-LS5.2-RD~CGzI.step
LQFP-64_L10.0-W10.0-P0.50-LS12.0-BL~LQFP-64_L10.0-W10.0-H1.4-LS12.0-P0.50~CGzI.step
Board~CGzI.step

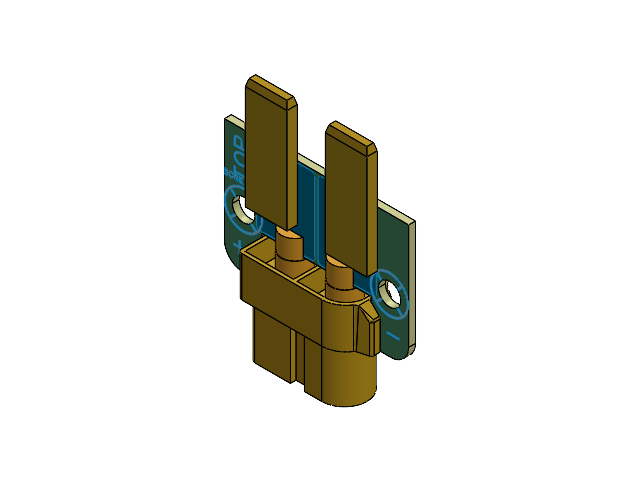
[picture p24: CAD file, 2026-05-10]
hardware/Tb48Battery/TB48Connector.SLDASM
XT60PM-F~XT60PM-F~cMRf.step
Board~1koO.step
TopCopper~1koO.step
BottomCopper~1koO.step
TopSilkscreen~1koO.step
BottomSilkscreen~1koO.step
InsertCoppers^TB48Connector

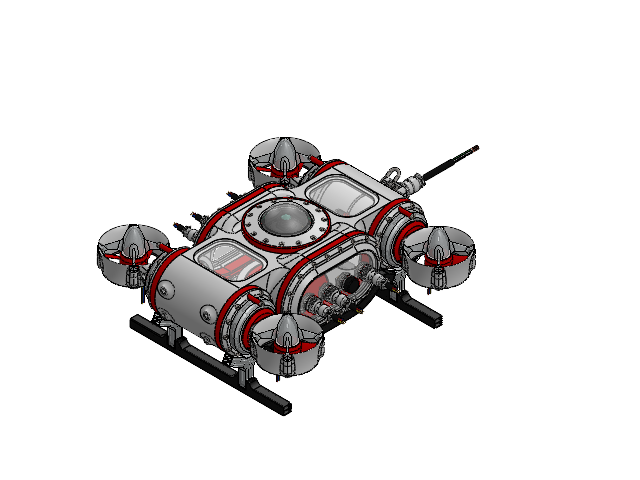
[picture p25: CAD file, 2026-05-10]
hardware/CabinASM.SLDASM
cross recessed countersunk head screws gb2 x 4
hex thin nut chamfered gradeab_bsi
BodyShell
BodyShellAcrylic x 4
TailAcrylicGasket
DomeCover x 2
USBCamera x 2
CameraShell x 2
hexagon socket head cap screws gb x 208
OringD70d4^CamModule x 2
DM3510 x 4
DriverConnector x 4
hexagon socket countersunk head screws gb M3L6 x 24
DriverMagnets x 8
D40L3GlassCover x 4
deep groove ball bearings gb x 4
BodyCover x 2
Conector CNC x 6
Conector CNC - Anillo x 6
Conector CNC - Tuerca x 6
RubberBand^EnsamblajeConectorGX16 x 6
Hat^EnsamblajeConectorGX16 x 6
Body005_1.step x 5
Body006_1.step x 10
Body001_1.step
Body_1.step
Flange^GX20-15 Jack
Body009_1.step x 10
Body006_2.step x 5
Body_2.step
Body001_2.step
Body004_2.step
M2.5x7-Screw.step
M2.5x7-Screw001.step
Body005_2.step
Wire^EnsamblajeConectorGX20
2312A x 4
Paddle x 4
Duct x 4
DuctFixCover^PaddleASM x 4
CovertMagnets(5x5+5x15)x4^PaddleASM x 4
deep groove ball bearings gb 6006 x 4
prevailing torque type with flange gb x 4
M4UBuckle x 2
Thread
O-Ring
BodyCoverAcrylicPlus
G14Manometer
Bracket

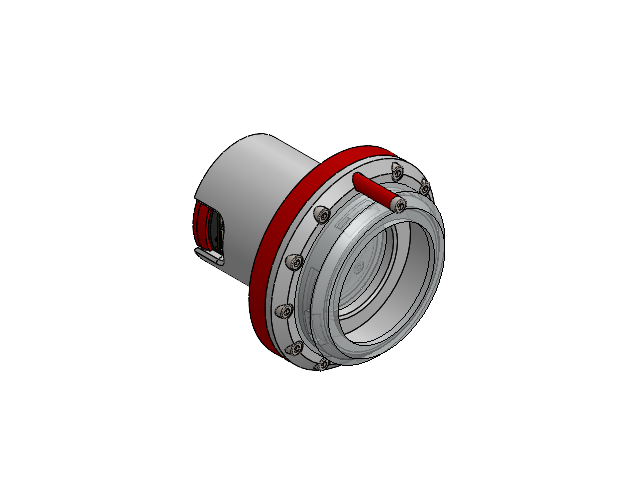
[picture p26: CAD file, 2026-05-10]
hardware/DriverArm/SingleArmASM.SLDASM
DM3510
DriverConnector
hexagon socket countersunk head screws gb M3L6 x 6
DriverMagnets
D40L3GlassCover
hexagon socket head cap screws gb x 21
deep groove ball bearings gb

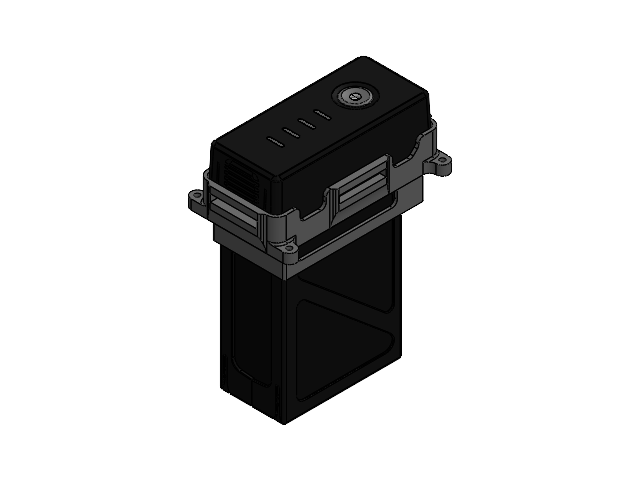
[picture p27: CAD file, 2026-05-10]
hardware/Tb48Battery/BatteryASM.SLDASM
TB48
BatteryCase
XT60PM-F~XT60PM-F~cMRf.step
Board~1koO.step
TopCopper~1koO.step
BottomCopper~1koO.step
TopSilkscreen~1koO.step
BottomSilkscreen~1koO.step
InsertCoppers^TB48Connector
hexagon socket head cap screws gb x 2

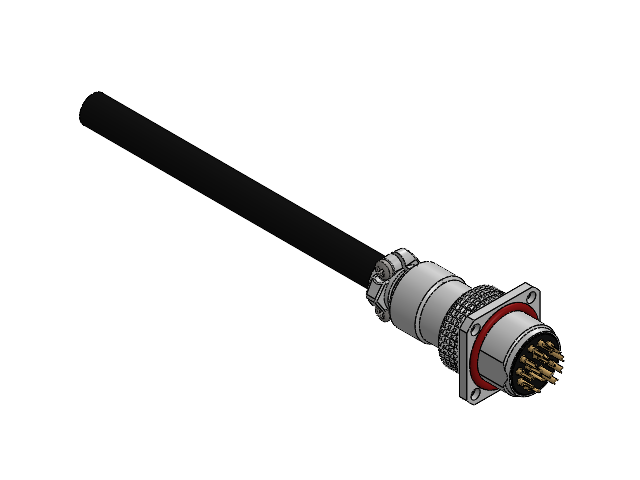
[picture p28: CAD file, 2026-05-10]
hardware/gx20-connector/EnsamblajeConectorGX20.SLDASM
Body005_1.step x 5
Body006_1.step x 10
Body001_1.step
Body_1.step
Flange^GX20-15 Jack
Body009_1.step x 10
Body006_2.step x 5
Body_2.step
Body001_2.step
Body004_2.step
M2.5x7-Screw.step
M2.5x7-Screw001.step
Body005_2.step
Wire^EnsamblajeConectorGX20

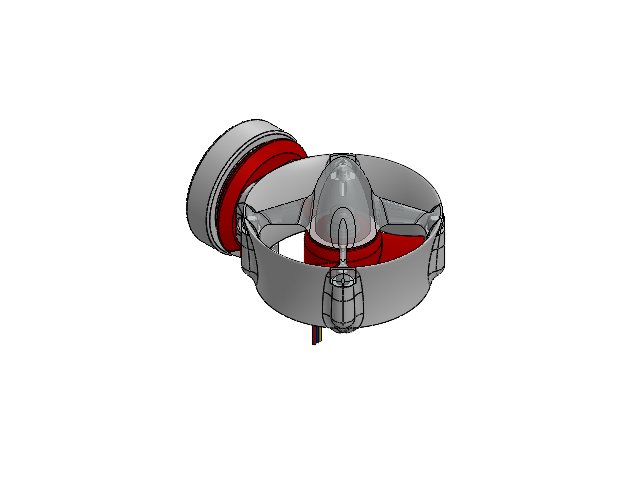
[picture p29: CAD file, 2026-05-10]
hardware/Propeller/PaddleASM.SLDASM
2312A
Paddle
Duct
DuctFixCover^PaddleASM
CovertMagnets(5x5+5x15)x4^PaddleASM
DriverMagnets
deep groove ball bearings gb 6006
prevailing torque type with flange gb
hexagon socket head cap screws gb x 15

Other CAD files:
hardware/BodyCover/BodyCoverEtc.SLDASM
hardware/MG90S/OneArmASM.SLDASM
hardware/gx16-connector/EnsamblajeConectorGX16.SLDASM
hardware/Acrylic/AcrylicCovers.DWG
hardware/Acrylic/AcrylicCovers.SLDDRW
hardware/BodyCover/BodyCover.SLDPRT
hardware/BodyCover/BodyCoverAcrylic.SLDPRT
hardware/BodyShell/BodyShell.SLDPRT
hardware/BodyShell/TailAcrylicGasket.SLDPRT
hardware/Camera/CameraShell.SLDPRT
hardware/Camera/DomeCover.SLDPRT
hardware/Camera/USBCamera.SLDPRT
hardware/Camera/elp-usb500w05g-fd100.stp
hardware/DM-H3510/DM3510.SLDPRT
hardware/DM-MC02/CtrBoard-H723.SLDASM
hardware/DM-MC02/CtrBoard-H723.STEP
hardware/DM-OrinNX/DM-OrinNX.SLDASM
hardware/DM-OrinNX/DM-OrinNX.STEP
hardware/DriverArm/D40L3GlassCover.SLDPRT
hardware/DriverArm/DriverConnector.SLDPRT
hardware/LED_Button16mm/Body.SLDPRT
hardware/LED_Button16mm/LED_Button_16mm.SLDASM
hardware/LED_Button16mm/LED_Button_16mm.STEP
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

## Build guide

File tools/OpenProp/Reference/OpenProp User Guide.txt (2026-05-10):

OpenProp User Guide
10/21/2013

Prof. Brenden Epps,     Thayer School of Engineering at Dartmouth College
Prof. Richard Kimball,  Maine Maritime Academy

------------------------------------------------------------------------------------------------
Setup:

1. Download OpenProp_v3.3.3.zip from the OpenProp website: http://engineering.dartmouth.edu/openprop .  

2. Move the zip file to any convenient parent directory:
 	(e.g. <parent> == /Users/bepps/Documents/) 

3. Unzip OpenProp_v3.3.3.zip.  The "OpenProp" folder should now appear in the "parent" directory: 
	(e.g. <OpenProp> == /Users/bepps/Documents/OpenProp_v3.3.3/)

------------------------------------------------------------------------------------------------
Running OpenProp at the command line:

1. OpenProp can be run at the Matlab command line using various function calls.  The usage 
   is illustrated in the examples folders:

	./Examples/Ex*

2.  Use the templates in the Example folders to get started on your design.  The basic commands
    are as follows:
	>> Run_input_script, 			       (creates pt data structure and pt.input)
	>> pt.design   = EppsOptimizer(pt.input);
	>> pt.states   = Analyze(pt,[0:0.1:10]);
	>> pt.geometry = Geometry(pt);

3. Users are encouraged to create a new folder for each propeller/turbine design they create.  

------------------------------------------------------------------------------------------------
Running OpenProp using the graphical user interface (GUI):

1. OpenProp can also be run using the graphical user interface (GUI).

2. In Matlab, change the working directory to the "OpenProp" folder. 

3. At the command line, type:
	 >> openprop

	This loads the Single Design GUI.  

4. To perform a single propeller/turbine design, input the desired inputs to the GUI, and 
   press the "Run OpenProp" button.

   To perform a parametric design study, choose "Parametric Study" from the pull-down menu in
   the top left corner of the GUI.

------------------------------------------------------------------------------------------------
GUI file structure and data input/output:

1. In OpenProp, all propeller/turbine data is saved in a data structure called "pt".  

2. Upon execution of a "Single Design" or "Parametric Study", OpenProp will look for the
   directory <OpenProp>/filename/ and will create that directory if it does not exist:
  	(e.g. /Users/bepps/Documents/OpenProp_v3.3.2/DefaultPropeller)

   The pt data structure is always saved in <OpenProp>/filename/filename.mat .

   NOTE: When running a "Single Design", the following data structures are overwritten:
		pt.filename
		pt.date
		pt.input
		pt.design
		pt.geometry
		pt.states
	When running a "Parametric Study", the following data structures are overwritten:
		pt.name
		pt.date
		pt.parinput
		pt.paroutput

	In order to avoid overwriting previous designs, change the "filename".

3. In the "Single Design" and "Parametric Study" modes, the GUI values can be saved by 
   pressing the "Save" button.  This creates the following files:

	<OpenProp>/filename/filename_GUIsd.mat   -- "Single Design"    GUI values
	<OpenProp>/filename/filename_GUIps.mat   -- "Parametric Study" GUI values

   Similarly, prior GUI values can be loaded using the "Load" button and then choosing the
   appropriate GUI mat file. 

   NOTE: These files are automatically created/overwritten at runtime (i.e. when the 
         "Run OpenProp" button is pressed).

4. After running OpenProp, the "pt" data structure can be loaded into the Matlab workspace by:
    	>> change the working directory to <OpenProp>/filename
	>> load filename.mat

------------------------------------------------------------------------------------------------
Command line data input/output:

1. In OpenProp, all propeller/turbine data is saved in a data structure called "pt". 
   When running at the command line, the user may choose to use shorthand for the 
   "input", "design", "geometry", and "states" data structures, as follows:
	pt = 
		pt.filename
		pt.date
		pt.i
		pt.d
		pt.g
		pt.s

	For an example of this notation, see ExP02_Propeller_Parametric_Study.

2. The default inputs are listed in OpenProp_default_inputs.m, and the default input data 
   structure is as follows.  Here, "999" indicates that a value must be specified by the user.
   The user can create in input data structure that contains some or all of the other optional
   inputs.  See EppsOptimizer.m, Analyze.m, Geometry.m, and AnalyzeGeometry.m to understand the usage of these inputs.

	-----------------------------------
	input =
                part1: '------ Performance inputs ------'
                    L: 999  (only used in turbine   case)	% tip speed ratio     (for propeller, L  = pi/Js)
                   Js: 999  (only used in propeller case)	% advance coefficient (for turbine,   Js = pi/L )
                   CT: 999  (only used in propeller case)	% desired total thrust coefficient (propeller plus duct)         (user may specify 'KT' or dimensional 'THRUST' instead)
                   CQ: 999  (only used in propeller case)	% desired total torque coefficient (optional, in lieu of 'CT')   (user may specify 'KQ' or dimensional 'TORQUE' instead)
								% Note: The    user must specify one of {'CT', 'KT', or 'THRUST'} to minimize torque for prescribed thrust,
								%       or the user must specify one of {'CQ', 'KQ', or 'TORQUE'} to maximize thrust for prescribed  torque. 
								% Note: For turbine case, 'CT' and 'CQ' are unnecessary and are ignored
                part2: '------ Geometry inputs ------'
                    Z: 999 					% number of blades
             Meanline: 'NACA a=0.8 (modified)'			% meanline  form  (may be given as cell array of same length as XR)
            Thickness: 'NACA 65A010'				% thickness form  (may be given as cell array of same length as XR)
                part3: '------ Blade/Inflow inputs ------'
                   XR: [1x10 double]				% radial ordinate / R 
                 XCoD: [1x10 double]				% chord / D 			at XR
                Xt0oD: [1x10 double]				% thickness / D			at XR
                t0oc0: 0.1   * [1 1 1 1 1 1 1 1 1 1]		% thickness / chord		at XR (optional, in lieu of Xt0oD) 
                  XCD: 0.008 * [1 1 1 1 1 1 1 1 1 1]		% section drag coefficient	at XR
                  XVA: [1 1 1 1 1 1 1 1 1 1]			% axial inflow velocity / Vs	at XR
                  XVT: [0 0 0 0 0 0 0 0 0 0]			% swirl inflow velocity / Vs	at XR
                 dXVA: [0 0 0 0 0 0 0 0 0 0]			% variation in axial inflow velocity / Vs at XR (for cavitation analysis)
               XCLmax: [1x10 double]				% max lift coefficient	at XR       (for chord optimization)
                   ri: [1x10 double]				% [m] radial ordinate in dimensional units!         (optional)
                  VAI: [1 1 1 1 1 1 1 1 1 1]			% axial inflow velocity / Vs              at ri (optional, in lieu of  'XVA')
                  VTI: [0 0 0 0 0 0 0 0 0 0]			% swirl inflow velocity / Vs              at ri (optional, in lieu of  'XVT')
                 dVAI: [0 0 0 0 0 0 0 0 0 0]			% variation in axial inflow velocity / Vs at ri (optional, in lieu of 'dXVA')
                part4: '------ Computational inputs ------'
       Propeller_flag: 999					% 0 == turbine, 1 == propeller
         Viscous_flag: 999					% 0 == viscous forces off (CD = 0), 1 == viscous forces on
             Hub_flag: 0					% 0 == no hub, 1 == hub
            Duct_flag: 0					% 0 == no duct, 1 == duct
           Chord_flag: 0					% 0 == do not optimize chord lengths, 1 == optimize chord
            Plot_flag: 0					% 0 == do not display plots, 1 == display plots
            Wake_flag: 0					% 0 == Horseshoe(...,Wrench(...)) analytic formulae, 1 == Wake_Horseshoe(...) numerical model
 EppsOptimizer02_flag: 1   (only used in propeller case)	% Propeller optimization method (choose one only): LL-Linear
 EppsOptimizer23_flag: 0   (only used in propeller case)	% Propeller optimization method (choose one only): LL-Newton (standard    hub drag model)
 EppsOptimizer53_flag: 0   (only used in propeller case)	% Propeller optimization method (choose one only): LL-Newton (variational hub drag model)
      Make2Dplot_flag: 1					% 1 == make 2D geometry plot
      Make3Dplot_flag: 1					% 1 == make 3D geometry plot 
      Make_Rhino_flag: 0					% 1 == make Rhino file
      Make_SWrks_flag: 0					% 1 == make SolidWorks file
    QuarterChord_flag: 0					% 0 == lifting line at mid-chord, 1 == lifting line at mid-chord (for geometry only)
            LSGeoCorr: 'none'					% propeller Lifting Surface Geometry Corrections		
          ChordMethod: 'CLmax'					% Method of chord optimization {'CLmax', 'ConeyPLL', 'FAST2011dCTP', 'FAST2011dVAC'}
		  EAR: 0 					% Expanded Area Ratio specification (for chord optimization), ignored if EAR = 0
                   Mp: 20					% number of panels radially
                   Np: 20					% number of panels chordwise
                 ITER: 50					% number of iterations in solvers 
                  HUF: 0					% hub unloading factor
                  TUF: 0					% tip unloading factor
                  Rhv: 0.5					% hub vortex radius / hub radius
           ALPHAstall: 8*pi/180					% [rad] stall angle of attack
                part5: '------ Dimensional inputs (SI units) ------'
                   Vs: 1					% [m/s] free-stream speed
                    R: 1					% [m]	rotor radius (may give     diameter D    instead)
                 Rhub: 0.2000					% [m]   hub radius   (may give hub diameter Dhub instead)
                   Dm: 2					% [m]   model diameter 
                  rho: 1000					% [kg/m^3] fluid density
                    H: 3.0480					% [m]   shaft centerline depth (for cavitation analysis)
                    g: 9.8100					% [m/s^2] gravitational constant (for cavitation analysis)
                 Patm: 101325					% [Pa]  atmospheric pressure (for cavitation analysis)
                   Pv: 2500					% [Pa]  vapor pressure (for cavitation analysis)
                part6: '------ Duct inputs ------'
             Rduct_oR: 1					% duct radius  			 (user may specify dimensional 'Rduct' instead)
             Cduct_oR: 1					% duct chord length		 (user may specify dimensional 'Cduct' instead)
             Xduct_oR: 0					% duct axial position downstream (user may specify dimensional 'Xduct' instead)
                  CDd: 0.008					% duct drag coefficient
                  TAU: 1      (only used in propeller case)	% thrust ratio == propeller thrust / total thrust 
	          CTD: 0      (only used in turbine   case)     % desired duct thrust coefficient for turbine case (user may specify 'KTD' or dimensional 'THRUSTduct' instead)

	-----------------------------------
	design = 

        part1: '------ Section properties, size (1,Mp) ------'
           RC: [1x20 double] 					% radial coordinate of control points / R
           DR: [1x20 double] 					% delta(RV)
            G: [1x20 double] 					% circulation / (2*pi*R*Vs)
          VAC: [1x20 double] 					%      axial free-stream speed / Vs
          VTC: [1x20 double]					% tangential free-stream speed / Vs
       UASTAR: [1x20 double] 					%      axial inducted velocity / Vs
       UTSTAR: [1x20 double] 					% tangential inducted velocity / Vs
        VSTAR: [1x20 double] 					% total inflow speed / Vs
        TANBC: [1x20 double] 					% tangent of free-stream  inflow angle, Beta
       TANBIC: [1x20 double] 					% tangent of wake-aligned inflow angle, BetaI
           CL: [1x20 double] 					% section lift coefficient
           CD: [1x20 double] 					% section drag coefficient
          CoD: [1x20 double] 					% chord / diameter
         t0oc: [1x20 double] 					% thickness / chord
         t0oD: [1x20 double] 					% thickness / diameter
        part2: '------ Other properties  ------'
    converged: 1		 				% 1 == solver converged, 0 == solver did not converge
    iteration: 7	 					% iteration number at conclusion of solver
           RV: [1x21 double] 					% radial coordinate of vortex lattice points / R
      Rhub_oR: 0.2000 						% Rhub / R
          EAR: 0.6058 						% expanded area ratio
           LM: -0.3950 						% Lagrange multiplier
         VMIV: 1.0000 						% volumetric mean inflow velocity / Vs
         VMWV: 1.1825 						% volumetric mean wake   velocity / Vs
       SIGMAs: 257.4518 					% cavitation number
        part3: '------ Performance metrics ------'
            L: 3.7714 						% tip speed ratio
           Js: 0.8330 						% advance coefficient
           KT: 0.1500 						% thrust  coefficient
           KQ: 0.0283 						% torque  coefficient
           CT: 0.5505 						% thrust  coefficient
           CQ: 0.2076 						% torque  coefficient
           CP: 0.7831 						% power   coefficient
          CTH: -0.0077 						% hub thrust coefficient
         EFFY: 0.7030 						% efficiency
       ADEFFY: 0.8908 						% actuator disk efficiency
           QF: 0.7892 						% quality factor (EFFY/ADEFFY)

	-----------------------------------
 	states = 

        part1: '------ Off-design states ------'
            L: [18x1 double]					% tip speed ratio
           Js: [18x1 double]					% advance coefficient
           RC: [1x20 double]					% radial coordinate of control points / R
          CoD: [1x20 double]					% section chord length / rotor diameter
            G: [18x20 double]
       UASTAR: [18x20 double]					% ALL OTHERS SAME AS "design"
       UTSTAR: [18x20 double]
        VSTAR: [18x20 double]
        TANBC: [18x20 double]
       TANBIC: [18x20 double]
        ALPHA: [18x20 double] 					% net angle of attack
           CL: [18x20 double]
           CD: [18x20 double]
        part2: '------ Numerical metrics ------'
    converged: [18x1 double]
    iteration: [18x1 double]
        part3: '------ Performance metrics ------'
           KT: [18x1 double]
           KQ: [18x1 double]
           CT: [18x1 double]
           CQ: [18x1 double]
           CP: [18x1 double]
         EFFY: [18x1 double]
         VMWV: [18x1 double]

	-----------------------------------
	ginput =
                part1: '------ Design piont inputs ------'
                    L: 999  (only used in turbine   case)	% design point tip speed ratio     (for propeller, L  = pi/Js)
                   Js: 999  (only used in propeller case)	% design point advance coefficient (for turbine,   Js = pi/L )
								% Note: If the design point is unknown, use Js = pitch/diameter at blade tip

                part2: '------ Rotor geometry inputs ------'
                    Z: 999 					% number of blades
              Rhub_oR: 999   % the user must specify one of the following: {Rhub_oR or (Rhub and R) or (Dhub and D) or Dhub_oD}

                part3: '------ Blade/Inflow inputs ------'

Note: The blade geometry table must be given either versus raw radii 'XR' or control point radii 'RC'
                   XR  		RC				% radial ordinate / R   
           (computed)    	RV               		% vortex point radii / R
           (computed)    	DR               		% vortex panel width / R
                 XCoD  		CoD				% chord / D 			
  (XPoD or XTHETArad) 		(PoD or THETArad)		% pitch/diameter or pitch angle [rad]
                  XVA   	VAC				% axial inflow velocity / Vs
                  XVT  	 	VTC				% swirl inflow velocity / Vs                
                   Mp						% number of panels radially (default Mp = 20)
           
Note: IF CLCD_flag == 0, then the Meanline and Thickness distributions must be given to determine the lift and drag characteristics
                  XCD   	CD				% section drag coefficient	at XR
                f0oc0   	f0oc    			% section camber / chord at XR
      (Xt0oD or t0oc0)		t0oc				% thickness / D  or  thickness / chord  at XR 
            dCLdALPHA		dCLdALPHA  			% lift curve slope [default: dCLdALPHA = 2*pi/(1 + 2/PAR) ], where PAR = propeller aspect ratio (computed)
 
      For both the XR or RC data tables, the user must also provide either:
 
            {'f0octilde','CLItilde', and 'alphaItilde'} 	% {ideal camber, ideal lift coefficient, and ideal angle of attack} versus XR or RC
      or    {'Meanline' and 'Thickness'}			% meanline and thickness forms, which may be given as cell array of same length as XR or RC

      ELSE  CLCD_flag == 1, then the lift and drag coefficients must be given, tabulated versus radius and angle of attack:     
                            Note: angle of attack is measured relative to blade pitch angle THETArad, such that ALPHA == 0 when the inflow angle BetaIC equals THETArad   
         	      RELMdata      				% M == number of RELM  radii            (typically RELM == XR, but RELM can by any radii)        
        	     ALPHAdata  				% N == number of ALPHA angles of attack 
           		CLdata  				% CL(RELM,ALPHA) data matrix, size[M,N]
          		CDdata  				% CD(RELM,ALPHA) data matrix, size[M,N]      
      ENDIF

                part4: '------ Computational inputs ------'
       Propeller_flag: 999					% 0 == turbine, 1 == propeller
         Viscous_flag: 999					% 0 == viscous forces off (CD = 0), 1 == viscous forces on
             Hub_flag: 0					% 0 == no hub, 1 == hub
            Duct_flag: 0					% 0 == no duct, 1 == duct
            Plot_flag: 0					% 0 == do not display plots, 1 == display plots
            Wake_flag: 0					% 0 == Horseshoe(...,Wrench(...)) analytic formulae, 1 == Wake_Horseshoe(...) numerical model
            CLCD_flag: 0                                        % 0 == use CLCD_vs_ALPHA.m , 1 == use CL and CD data given in ginput
            LSGeoCorr: 'Morgan1968'  (propeller default)	% propeller Lifting Surface Geometry Corrections {'none', 'Morgan1968', 'EckhardtMorgan1955', 'vanManen1958'}		
            LSGeoCorr: 'none'        (turbine   default)	% propeller Lifting Surface Geometry Corrections - not recommended with turbines	
                 ITER: 50					% number of iterations in solvers 
                  Rhv: 0.5					% hub vortex radius / hub radius
           ALPHAstall: 8*pi/180					% [rad] stall angle of attack

------------------------------------------------------------------------------------------------	
Tips and tricks:

1. To save keystrokes, unpack the pt data structure.  For example, to plot the design
   circulation distribution:
   
	>> d = pt.design;
	>> figure,
	>> plot(d.RC,d.G)

    Or to plot a turbine performance curve:

	>> s = pt.states;
	>> figure,
	>> plot(s.L,-s.CP)

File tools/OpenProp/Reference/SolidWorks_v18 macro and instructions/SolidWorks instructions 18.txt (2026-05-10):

SolidWorks instructions:
Created: Rob Damus,     9/24/2009
 Edited: Brenden Epps, 10/ 6/2009 

Follow these steps to create a solid propeller blade in SolidWorks:

___ Create your hub ----

1. Draw the hub in SolidWorks, and save it in a SolidWorks part document file

2. Copy your hub file and rename it something like hub_with_blades.swp

3. Open hub_with_blades.swp

4. Run the following steps to add the key blade to the hub:

--- Create the key blade ----

1. Export filename_SolidWorks.txt from the OpenProp Geometry function.
	-- Make sure that the trailing edge point (2Np-1) is the same as point (1), so all blade sections are closed contours.

2. Run the OpenProp SolidWorks macro:
	-- (In SolidWorks)  Tools > Macro > Edit
	-- Open SolidWorks_macro_v18.swp
	-- Press the play button
	-- This should result in a sketch of blade sections and guide curves over surface points.

3. Create Surface Loft of the SectionCurve1...SectionCurve21
	-- Select all 21 SectionCurves in the Feature Manager
	-- Insert > Surface > Loft  (orange loft button)
 	-- Select GuideCurves 1-6.  GuideCurve 7 is an artifact of Solidworks_macro_v14 and should be ignored in macro v18.
	-- Check "Merge tangent faces"
	-- Uncheck "Close loft"

3. Create Surface-Fill at tip
	-- Insert > Surface > Fill
	-- For Patch Boundary: select TipSectionCurve21
	-- For Constraint Curves: select all TipCurves
	-- Check "Fix up boundary" and "Optimize Surface"

4. Create Surface-Fill at root
	-- Insert > Surface > Fill
	-- For Patch Boundary: select RootSectionCurve1
	-- For Constraint Curves: select all RootCurves
	-- Check "Fix up boundary" and "Optimize Surface"

4. Knit surfaces into a solid
	-- Insert > Surface > Knit
	-- Select Surface-Loft, Boundary-Surface, Surface-Fill1, and Surface-Fill2
	-- Check "Try to form Solid"

If the stars align, you will generate a solid body for the blade, that will be accessible under the Solid Bodies node in the Feature Manager tree.

----- To create a propeller from the single blade -----

1. Draw the propeller axis
	-- Choose the line tool
	-- Select the Front Plane
	-- Select Horizontal orientation, "For construction", and "infinite length"
	-- Click on the origin to place the line along the X-axis
	-- Exit the sketch

2. Create Z blades
	-- Insert > Pattern/Mirror > Circular Pattern
	-- For the "Parameters": select the propeller axis, set the number of instances to Z, set the angle to 360 deg, and check "Equal spacing"
	-- For the "Bodies to Pattern": In the "Solid Bodies" folder in the Feature Manager tree, select "Surface-Knit1", which highlight the solid body of your propeller blade.
	-- 

3. Combine the blades and hub.
	-- In the Feature Manager tree, select the hub, key blade, and CirPattern (remaining blades).
	-- Insert > Features > Combine.
	-- Operation type is "Add"

4. Add a filet radius to the seam between blade and hub
	-- Insert > Features > Fillet/Round
	-- Fillet type = "Face fillet", Radius = 0.01 in, Items to fillet: select hub and blade
	-- Repeat this for each blade

1. Set the units to MKS or MMGS
	-- Tools > Options > Document Properties > Units
	-- Note: SolidWorks may not export dimensions correctly in MKS mode (i.e. The file says length is measured in meters, but dimensions are given in milimeters.)

___ Save STL file ----

1. File > Save as
	-- STL file format
	-- Note: click the "Options" button, and increase the resolution of the part for best 3D printing.

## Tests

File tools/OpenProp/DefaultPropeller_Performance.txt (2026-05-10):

					 DefaultPropeller_Performance.txt 

					 OpenProp Performance Table

Date and time: 2025-11-25 14:52:53

 r/R	 V*	 beta	 betai	 Gamma	 CL	 Sigma	 dBetai
0.220	 6.78	 47.37	 52.78	 0.7045	 0.634	 5.498	 13.93
0.259	 7.36	 42.64	 48.22	 0.7442	 0.587	 4.647	 14.25
0.299	 7.97	 38.63	 44.38	 0.7978	 0.553	 3.950	 14.16
0.338	 8.63	 35.21	 40.98	 0.8531	 0.522	 3.361	 13.91
0.378	 9.31	 32.29	 37.98	 0.9053	 0.491	 2.876	 13.55
0.417	 10.02	 29.77	 35.32	 0.9522	 0.462	 2.476	 13.12
0.457	 10.75	 27.59	 32.97	 0.9926	 0.434	 2.146	 12.66
0.496	 11.49	 25.69	 30.87	 1.0259	 0.408	 1.873	 12.18
0.536	 12.24	 24.02	 29.01	 1.0516	 0.383	 1.644	 11.71
0.575	 13.00	 22.54	 27.34	 1.0693	 0.360	 1.453	 11.25
0.615	 13.77	 21.22	 25.83	 1.0786	 0.339	 1.291	 10.80
0.654	 14.54	 20.04	 24.48	 1.0788	 0.319	 1.153	 10.38
0.694	 15.32	 18.99	 23.25	 1.0690	 0.301	 1.036	 9.97
0.733	 16.11	 18.03	 22.13	 1.0480	 0.285	 0.934	 9.59
0.773	 16.90	 17.17	 21.11	 1.0140	 0.269	 0.846	 9.23
0.812	 17.69	 16.38	 20.17	 0.9643	 0.255	 0.769	 8.89
0.852	 18.49	 15.66	 19.31	 0.8951	 0.240	 0.702	 8.57
0.891	 19.29	 14.99	 18.52	 0.7999	 0.224	 0.643	 8.27
0.931	 20.09	 14.38	 17.79	 0.6660	 0.207	 0.591	 7.99
0.970	 20.90	 13.82	 17.10	 0.4614	 0.208	 0.545	 7.72

r/R 	 [ ], radial position of control points / propeller radius.
V* 	 [m/s], total inflow velocity.
beta 	 [deg], undisturbed flow angle.
betai 	 [deg], hydrodynamic Pitch angle.
Gamma 	 [m^2/s], vortex sheet strength.
CL 	 [ ], section lift coefficient.
Sigma 	 [ ], cavitation number.
d_alpha  [deg], inflow variation bucket width.

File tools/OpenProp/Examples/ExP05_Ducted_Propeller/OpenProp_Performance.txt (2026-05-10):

					 OpenProp_Performance.txt 

					 OpenProp Performance Table

Date and time: 2025-11-26 20:56:29

 r/R	 V*	 beta	 betai	 Gamma	 CL	 Sigma	 dBetai
0.468	 7.56	 10.93	 29.69	 0.0633	 0.764	 4.484	 5.01
0.495	 8.12	 10.34	 28.18	 0.0636	 0.741	 3.887	 4.87
0.523	 8.49	 9.81	 27.22	 0.0644	 0.742	 3.558	 4.70
0.550	 8.91	 9.34	 26.33	 0.0652	 0.741	 3.234	 4.54
0.577	 9.34	 8.90	 25.48	 0.0662	 0.740	 2.939	 4.39
0.605	 9.79	 8.51	 24.66	 0.0671	 0.740	 2.677	 4.25
0.632	 10.24	 8.15	 23.87	 0.0680	 0.740	 2.446	 4.11
0.659	 10.69	 7.81	 23.13	 0.0688	 0.740	 2.242	 3.99
0.686	 11.15	 7.51	 22.43	 0.0696	 0.741	 2.062	 3.87
0.714	 11.60	 7.22	 21.77	 0.0703	 0.741	 1.904	 3.76
0.741	 12.06	 6.96	 21.16	 0.0709	 0.742	 1.763	 3.65
0.768	 12.51	 6.71	 20.59	 0.0714	 0.743	 1.637	 3.55
0.795	 12.96	 6.49	 20.07	 0.0719	 0.744	 1.525	 3.45
0.823	 13.41	 6.27	 19.59	 0.0722	 0.745	 1.424	 3.35
0.850	 13.86	 6.07	 19.14	 0.0725	 0.746	 1.334	 3.26
0.877	 14.30	 5.89	 18.72	 0.0726	 0.746	 1.252	 3.18
0.905	 14.75	 5.71	 18.32	 0.0726	 0.745	 1.178	 3.10
0.932	 15.18	 5.54	 17.92	 0.0723	 0.743	 1.111	 3.02
0.959	 15.61	 5.39	 17.49	 0.0715	 0.737	 1.051	 2.95
0.986	 16.20	 5.24	 16.81	 0.0699	 0.715	 0.977	 2.89

r/R 	 [ ], radial position of control points / propeller radius.
V* 	 [m/s], total inflow velocity.
beta 	 [deg], undisturbed flow angle.
betai 	 [deg], hydrodynamic Pitch angle.
Gamma 	 [m^2/s], vortex sheet strength.
CL 	 [ ], section lift coefficient.
Sigma 	 [ ], cavitation number.
d_alpha  [deg], inflow variation bucket width.

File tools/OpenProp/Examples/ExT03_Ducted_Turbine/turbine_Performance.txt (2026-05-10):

					 turbine_Performance.txt 

					 OpenProp Performance Table

Date and time: 2025-11-25 21:38:52

 r/R	 V*	 beta	 betai	 Gamma	 CL	 Sigma	 dBetai
0.278	 2.70	 27.50	 21.55	 -0.1368	 -1.033	 28.971	 15.43
0.315	 2.99	 24.67	 19.52	 -0.1855	 -1.027	 23.504	 13.98
0.352	 3.29	 22.34	 17.81	 -0.2114	 -1.023	 19.395	 12.77
0.389	 3.59	 20.40	 16.36	 -0.2268	 -1.020	 16.235	 11.74
0.426	 3.89	 18.75	 15.13	 -0.2369	 -1.017	 13.760	 10.85
0.463	 4.20	 17.35	 14.08	 -0.2440	 -1.015	 11.790	 10.08
0.500	 4.50	 16.13	 13.16	 -0.2495	 -1.013	 10.200	 9.41
0.537	 4.81	 15.07	 12.37	 -0.2542	 -1.012	 8.901	 8.82
0.574	 5.12	 14.14	 11.67	 -0.2583	 -1.011	 7.828	 8.29
0.611	 5.43	 13.31	 11.06	 -0.2623	 -1.010	 6.931	 7.82
0.648	 5.75	 12.58	 10.51	 -0.2661	 -1.009	 6.176	 7.40
0.685	 6.06	 11.92	 10.03	 -0.2700	 -1.008	 5.534	 7.03
0.722	 6.37	 11.32	 9.59	 -0.2740	 -1.008	 4.984	 6.68
0.759	 6.69	 10.78	 9.21	 -0.2779	 -1.007	 4.510	 6.37
0.796	 7.00	 10.29	 8.86	 -0.2819	 -1.007	 4.098	 6.09
0.833	 7.32	 9.84	 8.54	 -0.2857	 -1.007	 3.738	 5.83
0.870	 7.64	 9.43	 8.26	 -0.2892	 -1.006	 3.422	 5.59
0.907	 7.95	 9.05	 8.00	 -0.2922	 -1.006	 3.144	 5.37
0.944	 8.27	 8.70	 7.74	 -0.2946	 -1.006	 2.897	 5.16
0.981	 8.59	 8.38	 7.58	 -0.2952	 -1.006	 2.675	 4.97

r/R 	 [ ], radial position of control points / propeller radius.
V* 	 [m/s], total inflow velocity.
beta 	 [deg], undisturbed flow angle.
betai 	 [deg], hydrodynamic Pitch angle.
Gamma 	 [m^2/s], vortex sheet strength.
CL 	 [ ], section lift coefficient.
Sigma 	 [ ], cavitation number.
d_alpha  [deg], inflow variation bucket width.

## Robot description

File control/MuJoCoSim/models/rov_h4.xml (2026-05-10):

<mujoco model="rov_h4_underwater">
  <!-- ========== 模型总览 ==========
    四矢量推进器 ROV（H 形框架），坐标系：+x 前进，+y 左舷，+z 向上。
    机身：50×20×10 cm；四臂：沿 ±y，长 15 cm，直径 10 cm；推进器舱：高 10 cm，直径 10 cm，默认推力沿局部 +z。
    推进器绕局部 y 轴转动（铰链在臂末端），推力方向始终在 xz 平面内。
    淡水：option.density≈1000 kg/m³ 用于流体阻力/附加质量等；MuJoCo 流体模型不含静浮力（阿基米德力），
    因此不能单靠 geom 密度与水体密度相等实现“重力=浮力”。中性浮力采用各刚体 gravcomp="1" 抵消重力来模拟。
  -->

  <!-- compiler：角度单位、欧拉顺序、关节限位自动推断 -->
  <compiler angle="radian" eulerseq="xyz" autolimits="true"/>

  <!-- option：仿真步长、重力、流体密度/黏度、积分器、接触锥、全局风速（可代码里改） -->
  <option timestep="0.002" gravity="0 0 -9.81" density="1000" viscosity="0.001" integrator="implicitfast" cone="elliptic" wind="0 0 0"/>

  <!-- visual：视口光照与相机默认方位（仅显示，不影响动力学） -->
  <visual>
    <headlight diffuse="0.6 0.7 0.8" ambient="0.3 0.35 0.4"/>
    <global azimuth="140" elevation="-20"/>
  </visual>

  <!-- default：geom/joint/site/motor 的类默认属性，子元素未写明的从这里继承 -->
  <default>
    <geom type="cylinder" condim="3" friction="0.6 0.05 0.001" contype="1" conaffinity="1" density="1000" fluidshape="ellipsoid"/>
    <joint type="hinge" axis="0 1 0" damping="0.08" armature="0.002"/>
    <site size="0.015" rgba="0.9 0.9 0.2 0.5"/>
    <motor ctrllimited="true" ctrlrange="-1 1" forcelimited="true" forcerange="-30 30"/>
  </default>

  <!-- asset：纹理与材质（水面、地面棋盘格、机身/臂/推进器配色） -->
  <asset>
    <texture name="water_tex" type="2d" builtin="flat" rgb1="0.15 0.35 0.55" rgb2="0.1 0.25 0.4" width="1" height="1"/>
    <material name="water_mat" texture="water_tex" reflectance="0.1" texuniform="true"/>
    <texture name="floor_tex" type="2d" builtin="checker" rgb1="0.12 0.14 0.16" rgb2="0.18 0.2 0.22" width="256" height="256"/>
    <material name="floor_mat" texture="floor_tex" texrepeat="8 8" texuniform="true" reflectance="0.2"/>
    <material name="hull" rgba="0.25 0.28 0.32 1"/>
    <material name="arm" rgba="0.35 0.38 0.42 1"/>
    <material name="thruster" rgba="0.2 0.45 0.55 1"/>
  </asset>

  <!-- worldbody：世界坐标系下的静态场景 + ROV 根体 -->
  <worldbody>
    <!-- 定向光 -->
    <light pos="1 1 2" dir="-1 -1 -2" diffuse="1 1 1"/>
    <!-- 水底参考平面（z=-3） -->
    <geom name="floor" type="plane" size="5 5 0.01" material="floor_mat" pos="0 0 -3"/>
    <!-- 水面示意（z=0），无碰撞；ROV 在水下初始化 -->
    <geom name="water_surface" type="plane" size="6 6 0.01" material="water_mat" pos="0 0 0" contype="0" conaffinity="0" rgba="0.2 0.5 0.7 0.25"/>

    <!-- rov：整机浮动基；gravcomp 模拟中性浮力（抵消重力） -->
    <body name="rov" pos="0 0 -0.8" gravcomp="1">
      <!-- 6 自由度自由关节：基体位姿 -->
      <freejoint name="rov_free"/>
      <!-- 惯性由子 geom 密度自动合成；总排水体积约 1.585e-2 m^3 => 中性浮力质量约 15.85 kg -->
      <!-- imu：姿态/加速度/角速度传感器挂载点（机体原点） -->
      <site name="imu" type="sphere" pos="0 0 0" size="0.012" rgba="1 0.8 0 0.9"/>
      <!-- pressure_port：深度/静压推算用参考点（机身下方） -->
      <site name="pressure_port" pos="0 0 -0.05" type="sphere" size="0.008" rgba="0 1 0.5 0.7"/>

      <!-- 机身（H 形横梁）：50×20×10 cm 长方体 -->
      <geom name="hull" type="box" size="0.25 0.1 0.05" material="hull" density="1000" fluidshape="ellipsoid"/>

      <!-- 四臂：圆柱沿 ±y，直径 10 cm，臂长 15 cm，左右对称布置在 x=±0.2 -->
      <!-- 后左臂：x=-0.2，y 从机身到 +y 外伸 -->
      <geom name="arm_nx_py" material="arm" fromto="-0.2 0.01 0 -0.2 0.25 0" size="0.05" density="1000" fluidshape="ellipsoid"/>
      <!-- 后右臂：x=-0.2，y 从机身到 -y 外伸 -->
      <geom name="arm_nx_ny" material="arm" fromto="-0.2 -0.1 0 -0.2 -0.25 0" size="0.05" density="1000" fluidshape="ellipsoid"/>
      <!-- 前左臂：x=+0.2，y 从机身到 +y 外伸 -->
      <geom name="arm_px_py" material="arm" fromto="0.2 0.1 0 0.2 0.25 0" size="0.05" density="1000" fluidshape="ellipsoid"/>
      <!-- 前右臂：x=+0.2，y 从机身到 -y 外伸 -->
      <geom name="arm_px_ny" material="arm" fromto="0.2 -0.1 0 0.2 -0.25 0" size="0.05" density="1000" fluidshape="ellipsoid"/>

      <!-- ========== 四推进器子体：每臂末端一个矢量舱，绕局部 y 铰链；局部 +z 为推力轴 ========== -->
      <!-- 后左外推进器：x=-0.2, y=+0.25 -->
      <body name="thr_nx_py" pos="-0.2 0.25 0" gravcomp="1">
        <joint name="thr_nx_py_yaw" limited="true" range="-3.1415926 3.1415926"/>
        <geom name="geom_thr_nx_py" type="cylinder" size="0.05 0.05" zaxis="0 0 1" material="thruster" density="1000" fluidshape="ellipsoid" contype="0" conaffinity="0"/>
        <site name="site_thr_nx_py" pos="0 0 0.05" zaxis="0 0 1" size="0.02"/>
      </body>
      <!-- 后右外推进器：x=-0.2, y=-0.25 -->
      <body name="thr_nx_ny" pos="-0.2 -0.25 0" gravcomp="1">
        <joint name="thr_nx_ny_yaw" limited="true" range="-3.1415926 3.1415926"/>
        <geom name="geom_thr_nx_ny" type="cylinder" size="0.05 0.05" zaxis="0 0 1" material="thruster" density="1000" fluidshape="ellipsoid" contype="0" conaffinity="0"/>
        <site name="site_thr_nx_ny" pos="0 0 0.05" zaxis="0 0 1" size="0.02"/>
      </body>
      <!-- 前左外推进器：x=+0.2, y=+0.25 -->
      <body name="thr_px_py" pos="0.2 0.25 0" gravcomp="1">
        <joint name="thr_px_py_yaw" limited="true" range="-3.1415926 3.1415926"/>
        <geom name="geom_thr_px_py" type="cylinder" size="0.05 0.05" zaxis="0 0 1" material="thruster" density="1000" fluidshape="ellipsoid" contype="0" conaffinity="0"/>
        <site name="site_thr_px_py" pos="0 0 0.05" zaxis="0 0 1" size="0.02"/>
      </body>
      <!-- 前右外推进器：x=+0.2, y=-0.25 -->
      <body name="thr_px_ny" pos="0.2 -0.25 0" gravcomp="1">
        <joint name="thr_px_ny_yaw" limited="true" range="-3.1415926 3.1415926"/>
        <geom name="geom_thr_px_ny" type="cylinder" size="0.05 0.05" zaxis="0 0 1" material="thruster" density="1000" fluidshape="ellipsoid" contype="0" conaffinity="0"/>
        <site name="site_thr_px_ny" pos="0 0 0.05" zaxis="0 0 1" size="0.02"/>
      </body>
    </body>
  </worldbody>

  <!-- actuator：控制通道定义；前 4 路偏航伺服，后 4 路推力电机 -->
  <actuator>
    <!-- position：ctrl[0:4]，各推进器绕 y 轴目标角 [rad]；采用保守增益确保数值稳定 -->
    <position name="yaw_nx_py" joint="thr_nx_py_yaw" kp="80" kv="6" ctrlrange="-3.1415926 3.1415926"/>
    <position name="yaw_nx_ny" joint="thr_nx_ny_yaw" kp="80" kv="6" ctrlrange="-3.1415926 3.1415926"/>
    <position name="yaw_px_py" joint="thr_px_py_yaw" kp="80" kv="6" ctrlrange="-3.1415926 3.1415926"/>
    <position name="yaw_px_ny" joint="thr_px_ny_yaw" kp="80" kv="6" ctrlrange="-3.1415926 3.1415926"/>
    <!-- motor：ctrl[4:8]，推力作用在对应 site 局部 +z -->
    <motor name="thrust_nx_py" site="site_thr_nx_py" gear="0 0 25 0 0 0"/>
    <motor name="thrust_nx_ny" site="site_thr_nx_ny" gear="0 0 25 0 0 0"/>
    <motor name="thrust_px_py" site="site_thr_px_py" gear="0 0 25 0 0 0"/>
    <motor name="thrust_px_ny" site="site_thr_px_ny" gear="0 0 25 0 0 0"/>
  </actuator>

  <!-- sensor：仿真可读传感器，供观测/控制栈使用 -->
  <sensor>
    <!-- IMU：线加速度、角速度、磁强（地磁需外部注入时才有物理意义） -->
    <accelerometer name="imu_accel" site="imu"/>
    <gyro name="imu_gyro" site="imu"/>
    <magnetometer name="imu_mag" site="imu"/>
    <!-- 机体姿态四元数（相对世界） -->
    <framequat name="imu_quat" objtype="body" objname="rov"/>
    <!-- 机体线速度/角速度（世界系），补全 RL 常用状态 -->
    <framelinvel name="imu_linvel_world" objtype="site" objname="imu"/>
    <frameangvel name="imu_angvel_world" objtype="site" objname="imu"/>
    <!-- 世界坐标位置：imu 与压力口，用于深度/静压换算（水面 z=0 时 depth≈-pos_z） -->
    <framepos name="imu_pos_world" objtype="site" objname="imu"/>
    <framepos name="pressure_port_pos" objtype="site" objname="pressure_port"/>
    <!-- 各推进器矢量角 [rad]，用于推力分配与观测 -->
    <jointpos name="thr_nx_py_angle" joint="thr_nx_py_yaw"/>
    <jointpos name="thr_nx_ny_angle" joint="thr_nx_ny_yaw"/>
    <jointpos name="thr_px_py_angle" joint="thr_px_py_yaw"/>
    <jointpos name="thr_px_ny_angle" joint="thr_px_ny_yaw"/>
    <jointvel name="thr_nx_py_rate" joint="thr_nx_py_yaw"/>
    <jointvel name="thr_nx_ny_rate" joint="thr_nx_ny_yaw"/>
    <jointvel name="thr_px_py_rate" joint="thr_px_py_yaw"/>
    <jointvel name="thr_px_ny_rate" joint="thr_px_ny_yaw"/>
  </sensor>
</mujoco>

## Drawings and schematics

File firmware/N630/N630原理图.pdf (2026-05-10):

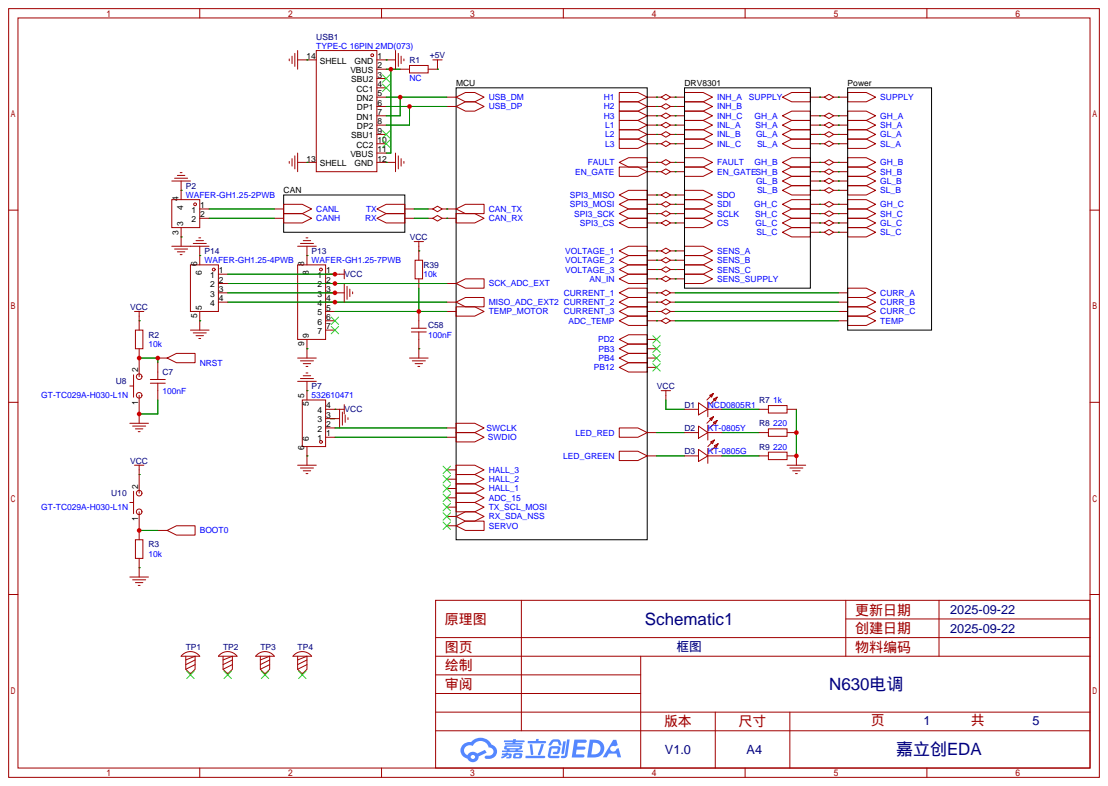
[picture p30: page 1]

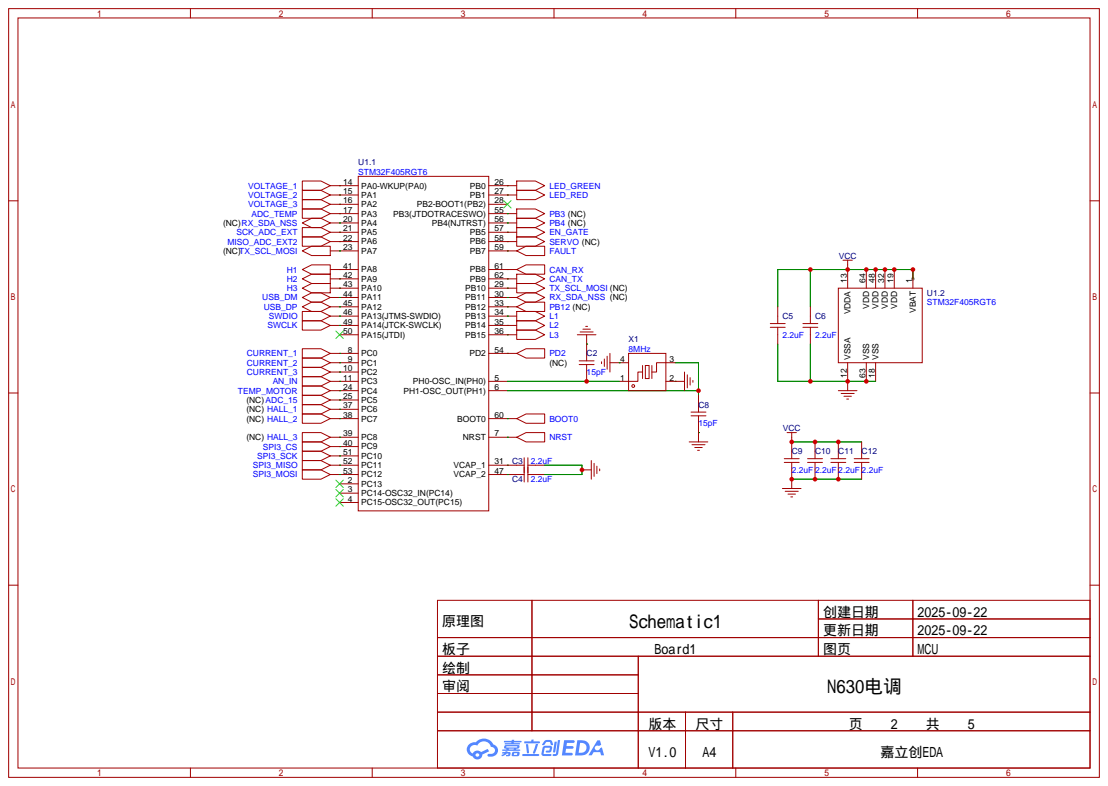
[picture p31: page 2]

VDD 19 VDD 32 VDD 48 VSS 63 VDD 64

原理图 | Schematic1 | 创建日期 | 2025-09-22

更新日期 | 2025-09-22

板子 | Board1 | 图页 | MCU
绘制 | | N630电调
审阅

AGND 28 PVDD1 29 SP2 30 SN2 31 SP1 32 SN1 33 SL-C 34 GL-C 35 SH-C 36 GH-C 37 BST-C 38 SL-B 39 GL-B 40 SH-B 41 GH-B 42 BST-B 43 SL-A 44 GL-A 45 SH-A 46 GH-A 47 BST-A 48 VDD-SPI 49 PH 50 PH 51 BST-BK 52 PVDD2 53 PVDD2 54 EN-BUCK 55 SS-TR 56 EP ⁵⁷

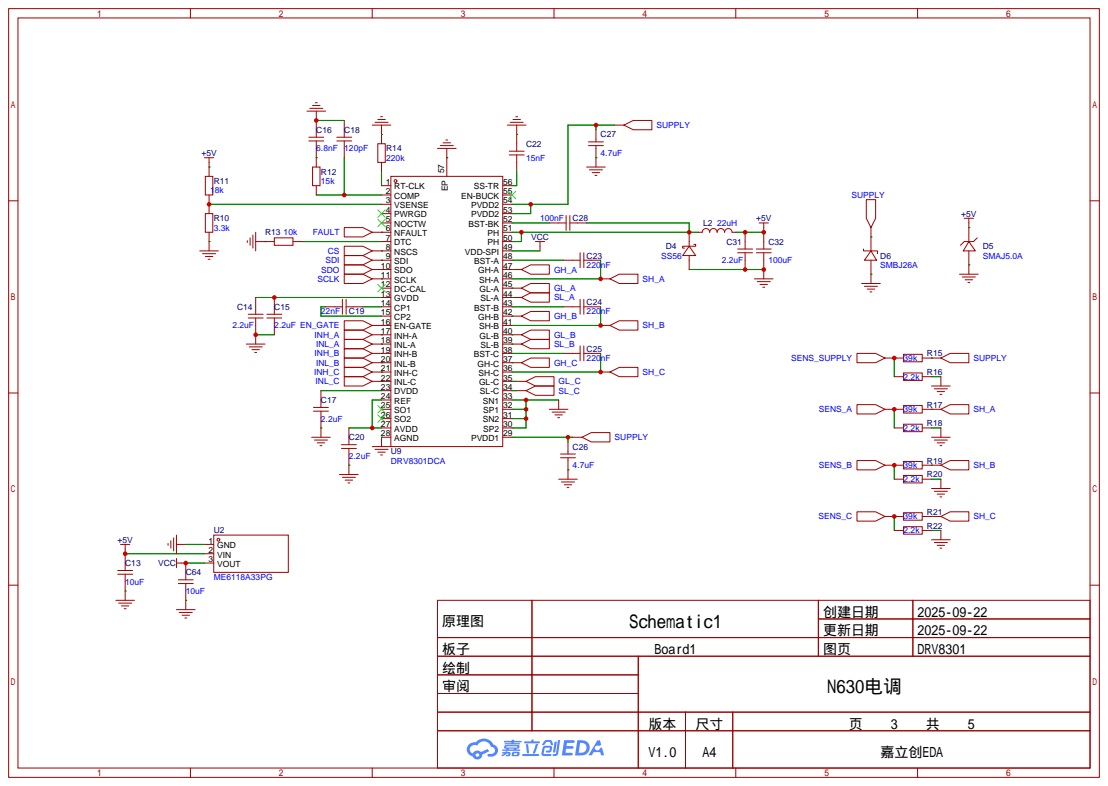
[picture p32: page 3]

原理图 | Schematic1 | 创建日期 | 2025-09-22

更新日期 | 2025-09-22

板子 | Board1 | 图页 | DRV8301
绘制 | | N630电调
审阅

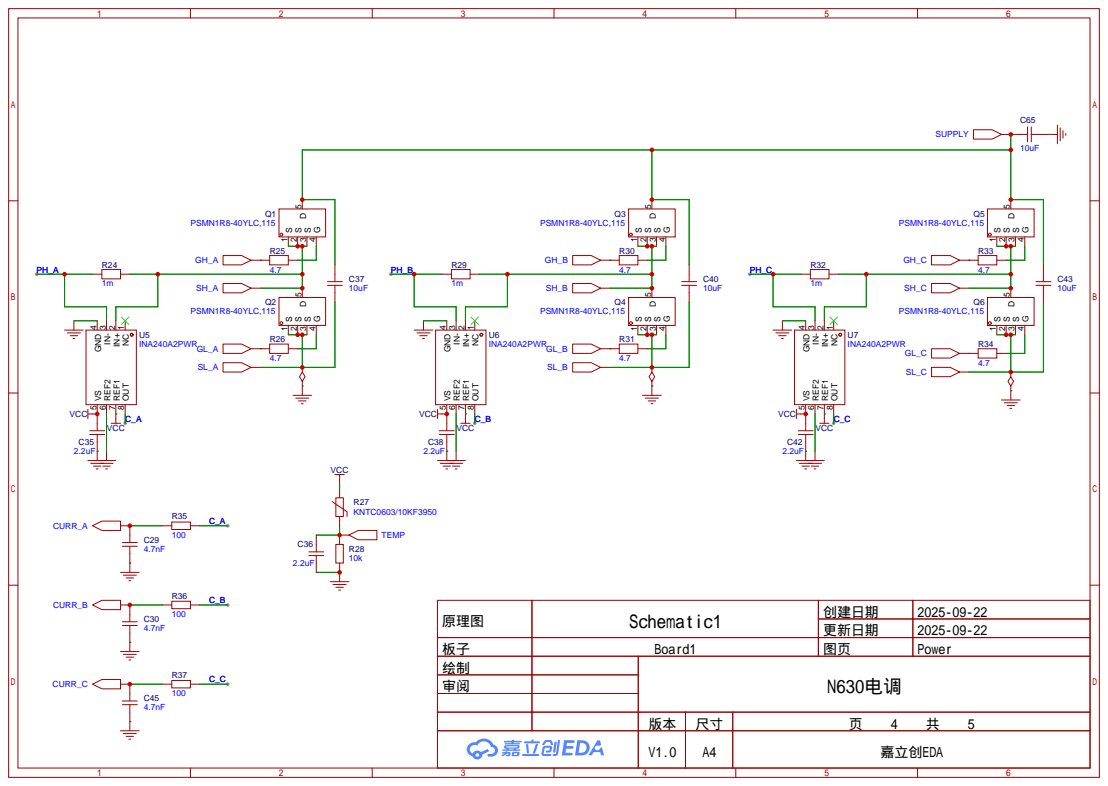
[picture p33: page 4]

原理图 | Schematic1 | 创建日期 | 2025-09-22

更新日期 | 2025-09-22

板子 | Board1 | 图页 | Power
绘制 | | N630电调
审阅

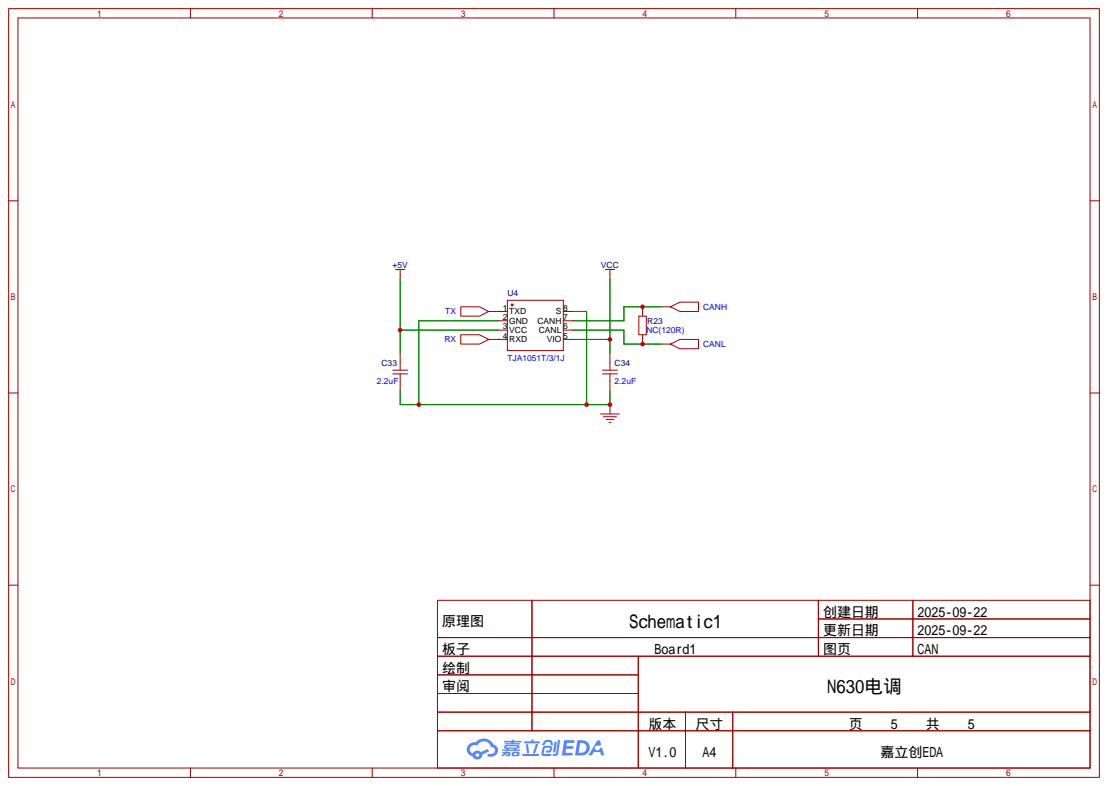
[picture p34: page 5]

原理图 | Schematic1 | 创建日期 | 2025-09-22

更新日期 | 2025-09-22

板子 | Board1 | 图页 | CAN
绘制 | | N630电调
审阅

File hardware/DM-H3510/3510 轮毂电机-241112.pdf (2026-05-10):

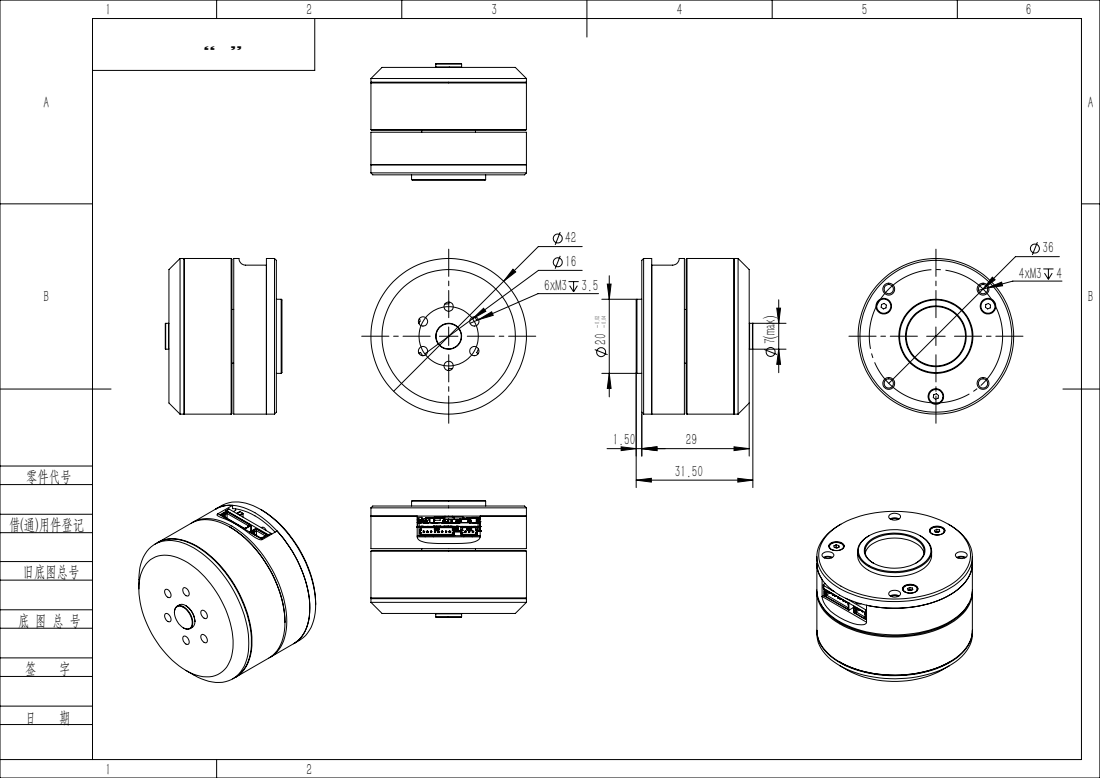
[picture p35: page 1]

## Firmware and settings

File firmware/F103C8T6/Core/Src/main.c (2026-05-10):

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
/* Includes ------------------------------------------------------------------*/
#include "main.h"

/* USER CODE BEGIN PTD */
typedef enum {
  ST_OFF_IDLE = 0,
  ST_OFF_LEVEL,
  ST_OFF_ANIM,
  ST_ON_IDLE,
  ST_ON_BLIP,
  ST_ON_LEVEL,
  ST_ON_ANIM,
} fsm_state_t;
/* USER CODE END PTD */

/* USER CODE BEGIN PD */
#define BTN_PORT          GPIOB
#define BTN_PIN           GPIO_PIN_13
#define IND_LED_PORT      GPIOB
#define IND_LED_PIN       GPIO_PIN_12
#define BAT_OUT_PORT      GPIOB
#define BAT_OUT_PIN       GPIO_PIN_9

#define LED1_PORT         GPIOB
#define LED1_PIN          GPIO_PIN_10
#define LED2_PORT         GPIOA
#define LED2_PIN          GPIO_PIN_7
#define LED3_PORT         GPIOA
#define LED3_PIN          GPIO_PIN_4
#define LED4_PORT         GPIOA
#define LED4_PIN          GPIO_PIN_1

#define DEBOUNCE_MS       20U
#define WINDOW_MS         4000U
#define LONG_PRESS_MS     1200U
#define BLINK_HALF_MS     250U      /* 2Hz: 250ms on / 250ms off */
#define ON_BLIP_MS        200U      /* ON 短按瞬间全灭时长 */
#define ANIM_STEP_MS      300U      /* 2s 动画分 4 步 */

#define ADC_BUF_LEN       32U
#define V_REF_MV          3300U     /* ADC 满量程 */
#define V_BAT0_MV         2310U     /* 0% 对应分压 2.61V */
#define V_BAT100_MV       3000U     /* 100% 对应分压 3.30V */

#define LOOP_TICK_MS      5U        /* 主循环节流周期 */
/* USER CODE END PD */

ADC_HandleTypeDef hadc1;
DMA_HandleTypeDef hdma_adc1;

TIM_HandleTypeDef htim2;

/* USER CODE BEGIN PV */
/* ADC DMA 循环采样缓冲 */
static volatile uint16_t adc_buf[ADC_BUF_LEN];

/* 按键去抖与边沿事件 */
static uint8_t  btn_stable      = 0;          /* 去抖后稳定电平 0/1 */
static uint8_t  btn_raw_last    = 0;
static uint32_t btn_change_ms   = 0;
static uint8_t  btn_consume     = 0;          /* 切换后忽略当前按住 */
static uint8_t  ev_pressed      = 0;          /* 本轮按下边沿 */
static uint8_t  ev_released     = 0;          /* 本轮释放边沿 */

/* 状态机 */
static fsm_state_t fsm           = ST_OFF_IDLE;
static uint32_t window_start_ms  = 0;          /* LEVEL 窗口起点 */
static uint32_t anim_start_ms    = 0;          /* ANIM 起点 */
static uint32_t blip_start_ms    = 0;          /* ON_BLIP 起点 */

/* 主循环节流 */
static uint32_t last_tick_ms     = 0;
/* USER CODE END PV */

void SystemClock_Config(void);
static void MX_GPIO_Init(void);
static void MX_DMA_Init(void);
static void MX_ADC1_Init(void);
static void MX_TIM2_Init(void);
/* USER CODE BEGIN PFP */
static void     update_button(uint32_t now);
static uint16_t adc_average_mv(void);
static int16_t  battery_percent(void);
static void     compute_level_pattern(uint8_t pat[4]);
static void     apply_leds(const uint8_t pat[4], uint8_t blink_on);
static void     render_off_anim(uint32_t elapsed, uint8_t pat[4]);
static void     render_on_anim(uint32_t elapsed, uint8_t pat[4]);
static void     fsm_step(uint32_t now);
static void     render_leds(uint32_t now);
/* USER CODE END PFP */

/**
  * @brief  The application entry point.
  * @retval int
  */
int main(void)
{

  /* MCU Configuration--------------------------------------------------------*/

  /* Reset of all peripherals, Initializes the Flash interface and the Systick. */
  HAL_Init();

  /* Configure the system clock */
  SystemClock_Config();

  /* Initialize all configured peripherals */
  MX_GPIO_Init();
  MX_DMA_Init();
  MX_ADC1_Init();
  MX_TIM2_Init();
  /* USER CODE BEGIN 2 */
  HAL_ADCEx_Calibration_Start(&hadc1);
  HAL_ADC_Start_DMA(&hadc1, (uint32_t *)adc_buf, ADC_BUF_LEN);

  /* 启动即关闭电池输出，确保上电安全 */
  HAL_GPIO_WritePin(BAT_OUT_PORT, BAT_OUT_PIN, GPIO_PIN_RESET);
  HAL_GPIO_WritePin(IND_LED_PORT, IND_LED_PIN, GPIO_PIN_RESET);
  HAL_GPIO_WritePin(LED1_PORT, LED1_PIN, GPIO_PIN_RESET);
  HAL_GPIO_WritePin(LED2_PORT, LED2_PIN, GPIO_PIN_RESET);
  HAL_GPIO_WritePin(LED3_PORT, LED3_PIN, GPIO_PIN_RESET);
  HAL_GPIO_WritePin(LED4_PORT, LED4_PIN, GPIO_PIN_RESET);

  fsm           = ST_OFF_IDLE;
  last_tick_ms  = HAL_GetTick();
  /* USER CODE END 2 */

  /* Infinite loop */
  /* USER CODE BEGIN WHILE */
  while (1)
  {
    uint32_t now = HAL_GetTick();
    if ((uint32_t)(now - last_tick_ms) >= LOOP_TICK_MS)
    {
      last_tick_ms = now;
      update_button(now);
      fsm_step(now);
      render_leds(now);
    }
    /* USER CODE END WHILE */

    /* USER CODE BEGIN 3 */
  }
  /* USER CODE END 3 */
}

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
/* USER CODE BEGIN 4 */

/* ------------------------------------------------------------------
 * 按键去抖与边沿检测：每个主循环 tick 调用一次
 * ------------------------------------------------------------------ */
static void update_button(uint32_t now)
{
  ev_pressed  = 0;
  ev_released = 0;

  uint8_t raw = (HAL_GPIO_ReadPin(BTN_PORT, BTN_PIN) == GPIO_PIN_SET) ? 1U : 0U;

  if (raw != btn_raw_last)
  {
    btn_raw_last  = raw;
    btn_change_ms = now;
  }

  if (raw != btn_stable && (uint32_t)(now - btn_change_ms) >= DEBOUNCE_MS)
  {
    btn_stable = raw;
    if (raw)
    {
      ev_pressed = 1;
    }
    else
    {
      ev_released = 1;
    }
  }
}

/* ------------------------------------------------------------------
 * ADC 取平均并换算成 mV
 * ------------------------------------------------------------------ */
static uint16_t adc_average_mv(void)
{
  uint32_t sum = 0;
  for (uint32_t i = 0; i < ADC_BUF_LEN; ++i)
  {
    sum += adc_buf[i];
  }
  uint32_t avg = sum / ADC_BUF_LEN;        /* 0..4095 */
  return (uint16_t)((avg * V_REF_MV) / 4095U);
}

/* ------------------------------------------------------------------
 * 电压百分比：2.61V=0%，3.30V=100%，线性
 * ------------------------------------------------------------------ */
static int16_t battery_percent(void)
{
  uint16_t mv = adc_average_mv();
  if (mv <= V_BAT0_MV)
  {
    return 0;
  }
  if (mv >= V_BAT100_MV)
  {
    return 100;
  }
  return (int16_t)(((uint32_t)(mv - V_BAT0_MV) * 100U) / (V_BAT100_MV - V_BAT0_MV));
}

/* ------------------------------------------------------------------
 * 把百分比映射为 4 路 LED 模式（0=灭 1=亮 2=2Hz 闪）
 *
 *   每 12.5% 一个分段（band n = (2*p)/25, n in 0..7）：
 *     n=0  [0,  12.5)  -> blink LED1
 *     n=1  [12.5,25)   -> solid LED1
 *     n=2  [25,  37.5) -> solid LED1, blink LED2
 *     ...
 *     n=7  [87.5,100)  -> all solid
 *   p == 0   单独处理：全灭
 *   p == 100 单独处理：全亮
 * ------------------------------------------------------------------ */
static void compute_level_pattern(uint8_t pat[4])
{
  pat[0] = pat[1] = pat[2] = pat[3] = 0;

  int16_t p = battery_percent();
  if (p <= 0)
  {
    return;
  }
  if (p >= 100)
  {
    pat[0] = pat[1] = pat[2] = pat[3] = 1;
    return;
  }

  int n          = (2 * p) / 25;          /* 0..7 */
  int full_solid = (n + 1) / 2;           /* 0..4 */
  int blink_at   = ((n & 1) == 0) ? 1 : 0;

  for (int i = 0; i < full_solid && i < 4; ++i)
  {
    pat[i] = 1;
  }
  if (blink_at && full_solid < 4)
  {
    pat[full_solid] = 2;
  }
}

/* ------------------------------------------------------------------
 * 把 pattern 写到 GPIO；blink_on 为闪烁全局相位（0/1）
 * ------------------------------------------------------------------ */
static void apply_leds(const uint8_t pat[4], uint8_t blink_on)
{
  GPIO_PinState s[4];
  for (int i = 0; i < 4; ++i)
  {
    if (pat[i] == 0U)
    {
      s[i] = GPIO_PIN_RESET;
    }
    else if (pat[i] == 1U)
    {
      s[i] = GPIO_PIN_SET;
    }
    else
    {
      s[i] = blink_on ? GPIO_PIN_SET : GPIO_PIN_RESET;
    }
  }
  HAL_GPIO_WritePin(LED1_PORT, LED1_PIN, s[0]);
  HAL_GPIO_WritePin(LED2_PORT, LED2_PIN, s[1]);
  HAL_GPIO_WritePin(LED3_PORT, LED3_PIN, s[2]);
  HAL_GPIO_WritePin(LED4_PORT, LED4_PIN, s[3]);
}

/* ------------------------------------------------------------------
 * OFF -> ON 动画（LED1~4 先全灭再依次点亮）
 * ------------------------------------------------------------------ */
static void render_off_anim(uint32_t elapsed, uint8_t pat[4])
{
  pat[0] = pat[1] = pat[2] = pat[3] = 0;
  if (elapsed >= ANIM_STEP_MS * 4U)
  {
    pat[0] = pat[1] = pat[2] = pat[3] = 1;
  }
  else if (elapsed >= ANIM_STEP_MS * 3U)
  {
    pat[0] = pat[1] = pat[2] = 1;
  }
  else if (elapsed >= ANIM_STEP_MS * 2U)
  {
    pat[0] = pat[1] = 1;
  }
  else if (elapsed >= ANIM_STEP_MS)
  {
    pat[0] = 1;
  }
}

/* ------------------------------------------------------------------
 * ON -> OFF 动画（LED4~1 先全亮再依次熄灭）
 * ------------------------------------------------------------------ */
static void render_on_anim(uint32_t elapsed, uint8_t pat[4])
{
  pat[0] = pat[1] = pat[2] = pat[3] = 1;
  if (elapsed >= ANIM_STEP_MS * 4U)
  {
    pat[0] = pat[1] = pat[2] = pat[3] = 0;
  }
  else if (elapsed >= ANIM_STEP_MS * 3U)
  {
    pat[1] = pat[2] = pat[3] = 0;
    pat[0] = 1;
  }
  else if (elapsed >= ANIM_STEP_MS * 2U)
  {
    pat[2] = pat[3] = 0;
    pat[0] = pat[1] = 1;
  }
  else if (elapsed >= ANIM_STEP_MS)
  {
    pat[3] = 0;
    pat[0] = pat[1] = pat[2] = 1;
  }
}

/* ------------------------------------------------------------------
 * 状态机推进：消费 ev_pressed / ev_released
 * ------------------------------------------------------------------ */
static void fsm_step(uint32_t now)
{
  /* 切换瞬间按键仍按住：吃掉这一次释放，不当作新一次短按 */
  if (ev_released && btn_consume)
  {
    btn_consume  = 0;
    ev_released  = 0;
  }

  switch (fsm)
  {
    case ST_OFF_IDLE:
      /* 必须先释放（短按）才进入 LEVEL：单纯按住不算 */
      if (ev_released)
      {
        fsm             = ST_OFF_LEVEL;
        window_start_ms = now;
      }
      break;

    case ST_OFF_LEVEL:
      if (ev_pressed)
      {
        fsm           = ST_OFF_ANIM;
        anim_start_ms = now;
      }
      else if ((uint32_t)(now - window_start_ms) >= WINDOW_MS)
      {
        fsm = ST_OFF_IDLE;
      }
      break;

    case ST_OFF_ANIM:
      if (btn_stable && (uint32_t)(now - anim_start_ms) >= LONG_PRESS_MS)
      {
        HAL_GPIO_WritePin(BAT_OUT_PORT, BAT_OUT_PIN, GPIO_PIN_SET);
        fsm         = ST_ON_IDLE;
        btn_consume = 1;        /* 等用户释放，期间不再触发短按 */
      }
      else if (ev_released)
      {
        /* 未到 2s 提前释放：回到 LEVEL，沿用原窗口剩余时间 */
        fsm = ST_OFF_LEVEL;
      }
      break;

    case ST_ON_IDLE:
      if (ev_released)
      {
        fsm            = ST_ON_BLIP;
        blip_start_ms  = now;
      }
      break;

    case ST_ON_BLIP:
      if ((uint32_t)(now - blip_start_ms) >= ON_BLIP_MS)
      {
        fsm             = ST_ON_LEVEL;
        window_start_ms = now;
      }
      break;

    case ST_ON_LEVEL:
      if (ev_pressed)
      {
        fsm           = ST_ON_ANIM;
        anim_start_ms = now;
      }
      else if ((uint32_t)(now - window_start_ms) >= WINDOW_MS)
      {
        fsm = ST_ON_IDLE;
      }
      break;

    case ST_ON_ANIM:
      if (btn_stable && (uint32_t)(now - anim_start_ms) >= LONG_PRESS_MS)
      {
        HAL_GPIO_WritePin(BAT_OUT_PORT, BAT_OUT_PIN, GPIO_PIN_RESET);
        fsm         = ST_OFF_IDLE;
        btn_consume = 1;
      }
      else if (ev_released)
      {
        fsm = ST_ON_LEVEL;
      }
      break;

    default:
      fsm = ST_OFF_IDLE;
      break;
  }

  ev_pressed  = 0;
  ev_released = 0;
}

/* ------------------------------------------------------------------
 * 根据当前状态刷新所有 LED（PB12 + LED1~4）
 * ------------------------------------------------------------------ */
static void render_leds(uint32_t now)
{
  uint8_t pat[4]   = {0, 0, 0, 0};
  uint8_t blink_on = (((now / BLINK_HALF_MS) & 1U) == 0U) ? 1U : 0U;
  uint8_t indicator;

  switch (fsm)
  {
    case ST_OFF_IDLE:
      /* 平时熄灭；按下时随之点亮，提供按键反馈 */
      indicator = btn_stable;
      break;

    case ST_OFF_LEVEL:
      indicator = 1;
      compute_level_pattern(pat);
      break;

    case ST_OFF_ANIM:
      indicator = 1;
      render_off_anim((uint32_t)(now - anim_start_ms), pat);
      break;

    case ST_ON_IDLE:
      indicator = 1;
      compute_level_pattern(pat);
      break;

    case ST_ON_BLIP:
      indicator = 1;
      /* pat 保持全 0，达到“短按熄灭所有 LED 再恢复”的瞬间效果 */
      break;

    case ST_ON_LEVEL:
      indicator = 1;
      compute_level_pattern(pat);
      break;

    case ST_ON_ANIM:
      indicator = 1;
      render_on_anim((uint32_t)(now - anim_start_ms), pat);
      break;

    default:
      indicator = 0;
      break;
  }

  HAL_GPIO_WritePin(IND_LED_PORT, IND_LED_PIN,
                    indicator ? GPIO_PIN_SET : GPIO_PIN_RESET);
  apply_leds(pat, blink_on);
}

/* USER CODE END 4 */
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


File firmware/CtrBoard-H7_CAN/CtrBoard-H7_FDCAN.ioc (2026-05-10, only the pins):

Mcu.UserName=STM32H723VGTx
PA11.Signal=USB_OTG_HS_DM
PA12.Signal=USB_OTG_HS_DP
PA13(JTMS/SWDIO).Signal=DEBUG_JTMS-SWDIO
PA14(JTCK/SWCLK).Signal=DEBUG_JTCK-SWCLK
PA5.Signal=SPI6_SCK
PA7.Signal=SPI6_MOSI
PB5.Signal=FDCAN2_RX
PB6.Signal=FDCAN2_TX
PD0.Signal=FDCAN1_RX
PD1.Signal=FDCAN1_TX
PD12.Signal=FDCAN3_RX
PH0-OSC_IN.Signal=RCC_OSC_IN
PH1-OSC_OUT.Signal=RCC_OSC_OUT

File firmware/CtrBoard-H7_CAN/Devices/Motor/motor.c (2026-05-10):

#include "motor.h"
#include "cmsis_os.h"

motor_t dmotors[4];

int float_to_uint(float x_float, float x_min, float x_max, int bits) {
    /* Converts a float to an unsigned int, given range and number of bits */
    float span = x_max - x_min;
    float offset = x_min;
    return (int)((x_float - offset) * ((float)((1 << bits) - 1)) / span);
}

float uint_to_float(int x_int, float x_min, float x_max, int bits) {
    /* converts unsigned int to float, given range and number of bits */
    float span = x_max - x_min;
    float offset = x_min;
    return ((float)x_int) * span / ((float)((1 << bits) - 1)) + offset;
}

void dm_motor_fbdata(motor_t *motor, uint8_t *rx_data) {
    motor->para.id = (rx_data[0]) & 0x0F;
    motor->para.state = (rx_data[0]) >> 4;
    motor->para.p_int = (rx_data[1] << 8) | rx_data[2];
    motor->para.v_int = (rx_data[3] << 4) | (rx_data[4] >> 4);
    motor->para.t_int = ((rx_data[4] & 0xF) << 8) | rx_data[5];
    motor->para.pos = uint_to_float(motor->para.p_int, -motor->tmp.PMAX, motor->tmp.PMAX, 16); // (-12.5,12.5)
    motor->para.vel = uint_to_float(motor->para.v_int, -motor->tmp.VMAX, motor->tmp.VMAX, 12); // (-45.0,45.0)
    motor->para.tor = uint_to_float(motor->para.t_int, -motor->tmp.TMAX, motor->tmp.TMAX, 12); // (-18.0,18.0)
    motor->para.Tmos = (float)(rx_data[6]);
    motor->para.Tcoil = (float)(rx_data[7]);
}

void mit_ctrl(hcan_t *hcan, motor_t *motor, uint16_t motor_id, float pos, float vel, float kp, float kd, float tor) {
    uint8_t data[8];
    uint16_t pos_tmp, vel_tmp, kp_tmp, kd_tmp, tor_tmp;
    uint16_t id = motor_id + MIT_MODE;

    pos_tmp = float_to_uint(pos, -motor->tmp.PMAX, motor->tmp.PMAX, 16);
    vel_tmp = float_to_uint(vel, -motor->tmp.VMAX, motor->tmp.VMAX, 12);
    tor_tmp = float_to_uint(tor, -motor->tmp.TMAX, motor->tmp.TMAX, 12);
    kp_tmp = float_to_uint(kp, KP_MIN, KP_MAX, 12);
    kd_tmp = float_to_uint(kd, KD_MIN, KD_MAX, 12);

    data[0] = (pos_tmp >> 8);
    data[1] = pos_tmp;
    data[2] = (vel_tmp >> 4);
    data[3] = ((vel_tmp & 0xF) << 4) | (kp_tmp >> 8);
    data[4] = kp_tmp;
    data[5] = (kd_tmp >> 4);
    data[6] = ((kd_tmp & 0xF) << 4) | (tor_tmp >> 8);
    data[7] = tor_tmp;

    fdcanx_send_data(hcan, id, data, 8);
}

void pos_ctrl(hcan_t *hcan, uint16_t motor_id, float pos, float vel) {
    uint16_t id;
    uint8_t *pbuf, *vbuf;
    uint8_t data[8];

    id = motor_id + POS_MODE;
    pbuf = (uint8_t *)&pos;
    vbuf = (uint8_t *)&vel;

    data[0] = *pbuf;
    data[1] = *(pbuf + 1);
    data[2] = *(pbuf + 2);
    data[3] = *(pbuf + 3);

    data[4] = *vbuf;
    data[5] = *(vbuf + 1);
    data[6] = *(vbuf + 2);
    data[7] = *(vbuf + 3);

    fdcanx_send_data(hcan, id, data, 8);
}

void spd_ctrl(hcan_t *hcan, uint16_t motor_id, float vel) {
    uint16_t id;
    uint8_t *vbuf;
    uint8_t data[4];

    id = motor_id + SPD_MODE;
    vbuf = (uint8_t *)&vel;

    data[0] = *vbuf;
    data[1] = *(vbuf + 1);
    data[2] = *(vbuf + 2);
    data[3] = *(vbuf + 3);

    fdcanx_send_data(hcan, id, data, 4);
}

void psi_ctrl(hcan_t *hcan, uint16_t motor_id, float pos, float vel, float cur) {
    uint16_t id;
    uint8_t *pbuf, *vbuf, *ibuf;
    uint8_t data[8];

    uint16_t u16_vel = vel * 100;
    uint16_t u16_cur = cur * 10000;

    id = motor_id + PSI_MODE;
    pbuf = (uint8_t *)&pos;
    vbuf = (uint8_t *)&u16_vel;
    ibuf = (uint8_t *)&u16_cur;

    data[0] = *pbuf;
    data[1] = *(pbuf + 1);
    data[2] = *(pbuf + 2);
    data[3] = *(pbuf + 3);

    data[4] = *vbuf;
    data[5] = *(vbuf + 1);

    data[6] = *ibuf;
    data[7] = *(ibuf + 1);

    fdcanx_send_data(hcan, id, data, 8);
}

void enable_motor_mode(hcan_t *hcan, uint16_t motor_id, uint16_t mode_id) {
    uint8_t data[8];
    uint16_t id = motor_id + mode_id;

    data[0] = 0xFF;
    data[1] = 0xFF;
    data[2] = 0xFF;
    data[3] = 0xFF;
    data[4] = 0xFF;
    data[5] = 0xFF;
    data[6] = 0xFF;
    data[7] = 0xFC;

    fdcanx_send_data(hcan, id, data, 8);
}

void disable_motor_mode(hcan_t *hcan, uint16_t motor_id, uint16_t mode_id) {
    uint8_t data[8];
    uint16_t id = motor_id + mode_id;

    data[0] = 0xFF;
    data[1] = 0xFF;
    data[2] = 0xFF;
    data[3] = 0xFF;
    data[4] = 0xFF;
    data[5] = 0xFF;
    data[6] = 0xFF;
    data[7] = 0xFD;

    fdcanx_send_data(hcan, id, data, 8);
}

void save_pos_zero(hcan_t *hcan, uint16_t motor_id, uint16_t mode_id) {
    uint8_t data[8];
    uint16_t id = motor_id + mode_id;

    data[0] = 0xFF;
    data[1] = 0xFF;
    data[2] = 0xFF;
    data[3] = 0xFF;
    data[4] = 0xFF;
    data[5] = 0xFF;
    data[6] = 0xFF;
    data[7] = 0xFE;

    fdcanx_send_data(hcan, id, data, 8);
}

void clear_err(hcan_t *hcan, uint16_t motor_id, uint16_t mode_id) {
    uint8_t data[8];
    uint16_t id = motor_id + mode_id;

    data[0] = 0xFF;
    data[1] = 0xFF;
    data[2] = 0xFF;
    data[3] = 0xFF;
    data[4] = 0xFF;
    data[5] = 0xFF;
    data[6] = 0xFF;
    data[7] = 0xFB;

    fdcanx_send_data(hcan, id, data, 8);
}

// 通过判断 motor 结构体中的控制模式来选择使能的模式，并添加偏移的ID
void dm_motor_enable(hcan_t *hcan, motor_t *motor) {
    switch (motor->ctrl.mode) {
    case MIT_MODE:
        enable_motor_mode(hcan, motor->id, MIT_MODE);
        break;
    case POS_MODE:
        enable_motor_mode(hcan, motor->id, POS_MODE);
        break;
    case SPD_MODE:
        enable_motor_mode(hcan, motor->id, SPD_MODE);
        break;
    case PSI_MODE:
        enable_motor_mode(hcan, motor->id, PSI_MODE);
        break;
    }
}

// 通过判断 motor 结构体中的控制模式来选择失能的模式，并添加偏移的ID
void dm_motor_disable(hcan_t *hcan, motor_t *motor) {
    switch (motor->ctrl.mode) {
    case MIT_MODE:
        disable_motor_mode(hcan, motor->id, MIT_MODE);
        break;
    case POS_MODE:
        disable_motor_mode(hcan, motor->id, POS_MODE);
        break;
    case SPD_MODE:
        disable_motor_mode(hcan, motor->id, SPD_MODE);
        break;
    case PSI_MODE:
        disable_motor_mode(hcan, motor->id, PSI_MODE);
        break;
    }
    // dm_motor_clear_para(motor);
}

// 通过判断 motor 结构体中的控制模式来选择清除错误的模式，并添加偏移的ID
void dm_motor_clear_err(hcan_t *hcan, motor_t *motor) {
    switch (motor->ctrl.mode) {
    case MIT_MODE:
        clear_err(hcan, motor->id, MIT_MODE);
        break;
    case POS_MODE:
        clear_err(hcan, motor->id, POS_MODE);
        break;
    case SPD_MODE:
        clear_err(hcan, motor->id, SPD_MODE);
        break;
    case PSI_MODE:
        clear_err(hcan, motor->id, PSI_MODE);
        break;
    }
}
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

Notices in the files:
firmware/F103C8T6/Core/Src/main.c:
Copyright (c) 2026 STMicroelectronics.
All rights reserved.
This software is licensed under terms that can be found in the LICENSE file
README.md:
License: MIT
